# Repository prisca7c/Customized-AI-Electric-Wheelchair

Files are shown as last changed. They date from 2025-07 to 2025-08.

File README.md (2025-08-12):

# Customized-AI-Electric-Wheelchair

>PRISCA CHIEN | U0741Q95Y02
>
>July 27 2025
---

Manual wheelchair turned electric! This wheelchair uses electronic components such as modules and a PCB to make this wheelchair much for user interactive (and helps make life easier when you can't walk). 
I built this custom wheelchair because electric wheelchairs cost too much. Also it would be a great gift to my grandpa as he has Parkinson's disease. It has most of the functions on a regular wheelchair (motors, sound, speed, SOS, etc) AND I will be using AI as a healthcare tool in this project. 

---

## Full 3D Model of Wheelchair with Electronics (will not have those cuffs IRL 💀)

## PCB Schematic

## PCB Wiring Diagram (strapping 24V fan on just in case it does overheat), back copper pours for 24V, front copper pours for 12V I can't fit the wires if they're too large

## 3D View of PCB


---

# Bill of Materials (BOM)

| Reference | Qty | Description | Footprint | Purchase Link | Status |
|---|-----|---|---|---|---|
| C1,C2,C3,C4,C6,C20,C23,C25 | 8 | Polarized Capacitor | CP_Radial_D5.0mm_P2.50mm | [AliExpress](https://www.aliexpress.com/item/1005002524973878.html) | |
| C5,C7,C8,C9,C10,C11,C12,C13,C14,C15,C16,C17,C18,C19,C22,C24 | 16 | Ceramic Capacitor | C_0603_1608Metric | [AliExpress](https://www.aliexpress.com/item/33000528620.html) | |
| C21 | 1 | Ceramic Capacitor (45°) | C_0603_1608Metric | [AliExpress](https://www.aliexpress.com/item/33000528620.html) | |
| D1 | 1 | TVS Diode | D_SMA | [AliExpress](https://www.aliexpress.com/item/1005002276080010.html) | |
| D2,D3,D4,D5,D8,D9,D10,D11,D12,D13,D14,D15,D16,D17,D18,D19 | 16 | Schottky Diode | D_SMA | [AliExpress](https://www.aliexpress.com/item/4001272645647.html) | |
| D6,D7 | 2 | LED | LED_D5.0mm | - | ✅ Have |
| F1 | 1 | Fuse | Fuse_BelFuse_0ZRE0005FF | - | ✅ Have |
| J1 | 1 | Buck Converter 24V→5V | PinSocket_1x04_P2.54mm | [AliExpress](https://www.aliexpress.com/item/1005006648976219.html) | |
| J2 | 1 | Buck Converter 24V→12V | FanPinHeader_1x04_P2.54mm | [AliExpress](https://www.aliexpress.com/item/1005004705881343.html) | |
| J3 | 1 | ICSP Programming Header | PinHeader_2x03_P2.54mm | - | ✅ Have |
| J4 | 1 | USB Serial | PinHeader_1x06_P1.00mm | - | ✅ Have |
| J5 | 1 | Raspberry Pi Zero | Harwin_M20-7812045_2x20 | [AliExpress](https://www.aliexpress.com/item/1005005792181612.html) | |
| J8 | 1 | Microphone | PinHeader_1x03_P1.00mm | [AliExpress](https://www.aliexpress.com/item/4001293896057.html) | |
| J9 | 1 | TFT 3.5" Display | PinHeader_1x14_P1.00mm | [AliExpress](https://www.aliexpress.com/item/1005008990800806.html) | |
| J10 | 1 | MPU6050 IMU | PinSocket_1x08_P2.54mm | [AliExpress](https://www.aliexpress.com/item/1005005682188615.html) | |
| J11 | 1 | DS3231 RTC | PinSocket_1x06_P2.54mm | [AliExpress](https://www.aliexpress.com/item/1005007143542894.html) | |
| J12 | 1 | Ultrasonic Sensor 1 | PinHeader_1x04_P1.00mm | - | ✅ Have |
| J13 | 1 | Ultrasonic Sensor 2 | PinHeader_1x04_P1.00mm | - | ✅ Have |
| J14 | 1 | Ultrasonic Sensor 3 | PinHeader_1x04_P1.00mm | - | ✅ Have |
| J15 | 1 | GPS Module | PinHeader_1x04_P1.00mm | [AliExpress](https://www.aliexpress.com/item/1005006459556070.html) | |
| J16 | 1 | Joystick Control | PinHeader_1x05_P1.00mm | - | ✅ Have |
| J17 | 1 | Temperature Sensor 1 | PinHeader_1x03_P1.00mm | - | ✅ Have |
| J18 | 1 | Temperature Sensor 2 | PinHeader_1x03_P1.00mm | - | ✅ Have |
| J19 | 1 | Servo 1 | PinHeader_1x02_P1.00mm | - | ✅ Have |
| J20 | 1 | Servo 2 | PinHeader_1x02_P1.00mm | - | ✅ Have |
| J21 | 1 | Linear Actuator | PinHeader_1x02_P1.00mm | - | ✅ Have |
| J22 | 1 | Audio Amplifier (LM386) | PinHeader_1x06_P1.00mm | [AliExpress](https://www.aliexpress.com/item/1005007577064258.html) | |
| J23 | 1 | Speaker | PinHeader_1x02_P1.00mm | [AliExpress](https://www.aliexpress.com/item/1005007504226811.html) | |
| J24 | 1 | XT60-M Power Connector | AMASS_XT60-M | [AliExpress](https://www.aliexpress.com/item/1005008955682135.html) | |
| J25,J26 | 2 | Motor Power Terminals | TerminalBlock_Phoenix_MKDS | [AliExpress](https://www.aliexpress.com/item/1005003179482974.html) | |
| Q1,Q2,Q3,Q4 | 4 | BSS138 MOSFET | SOT-23 | [AliExpress](https://www.aliexpress.com/item/1005009546772808.html) | |
| R1-R26 | 26 | Resistor | R_0603_1608Metric | - | ✅ Have |
| SW1 | 1 | SPST Switch | SW_PUSH-12mm | [AliExpress](https://www.aliexpress.com/item/1005006921918648.html) | |
| SW2-SW9 | 8 | Push Button | SW_PUSH-12mm | [AliExpress](https://www.aliexpress.com/item/1005007791349282.html) | |
| U1 | 1 | LM7805 Voltage Regulator | TO-220-3_Vertical | [AliExpress](https://www.aliexpress.com/item/10000200087213.html) | |
| U2 | 1 | AMS1117-3.3 Regulator | SOT-223-3_TabPin2 | [AliExpress](https://www.aliexpress.com/item/1005005774011848.html) | |
| U3 | 1 | ATMEGA2560-16AU MCU | TQFP100-0.5-14X14MM | [Digi-Key](https://www.digikey.ca/en/products/detail/microchip-technology/ATMEGA2560-16AU/735455) | |
| U4,U5,U6,U7 | 4 | BTS7960B Motor Driver | DPAK127P1490X440-8N | [AliExpress](https://www.aliexpress.com/item/1005006757604804.html) | |
| U9,U10 | 2 | L298N Motor Driver | TO-220-15_P2.54x2.54mm | [AliExpress](https://www.aliexpress.com/item/1462773567.html) | |
| U11 | 1 | ESP32-C3-MINI WiFi Module | XCVR_ESP32-C3-MINI-1-N4 | [AliExpress](https://www.aliexpress.com/item/1005007446928015.html) | |
| Y1 | 1 | Crystal Oscillator | Crystal_HC49-4H_Vertical | [AliExpress](https://www.aliexpress.com/item/1005002830871853.html) | |

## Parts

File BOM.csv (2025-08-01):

Reference | Qty | Value | DNP | Exclude from BOM | Exclude from Board | Footprint | Datasheet
C1,C2,C3,C4,C6,C20,C23,C25 | 8 | C_Polarized |  |  |  | Capacitor_THT:CP_Radial_D5.0mm_P2.50mm | https://www.aliexpress.com/item/1005002524973878.html
C5,C7,C8,C9,C10,C11,C12,C13,C14,C15,C16,C17,C18,C19,C22,C24 | 16 | C |  |  |  | Capacitor_SMD:C_0603_1608Metric | https://www.aliexpress.com/item/33000528620.html
C21 | 1 | C_45deg |  |  |  | Capacitor_SMD:C_0603_1608Metric | https://www.aliexpress.com/item/33000528620.html
D1 | 1 | D_TVS |  |  |  | Diode_SMD:D_SMA | https://www.aliexpress.com/item/1005002276080010.html
D2,D3,D4,D5,D8,D9,D10,D11,D12,D13,D14,D15,D16,D17,D18,D19 | 16 | D_Schottky |  |  |  | Diode_SMD:D_SMA | https://www.aliexpress.com/item/4001272645647.html
D6,D7 | 2 | LED |  |  |  | LED_THT:LED_D5.0mm | ~already have
F1 | 1 | Fuse |  |  |  | Fuse:Fuse_BelFuse_0ZRE0005FF_L8.3mm_W3.8mm | ~already have
H1,H4 | 2 | MountingHole |  | Excluded from BOM |  | MountingHole:MountingHole_2.7mm_M2.5 | ~
H5,H6,H7,H8 | 4 | MountingHole_Pad |  | Excluded from BOM |  | MountingHole:MountingHole_3.2mm_M3_Pad | ~
H9,H10,H11,H12 | 4 | MountingHole_Pad |  | Excluded from BOM |  | MountingHole:MountingHole_3.2mm_M3_Pad_Via | ~
J1 | 1 | Buck_Converter_24V-5V |  |  |  | Connector_PinSocket_2.54mm:PinSocket_1x04_P2.54mm_Vertical_SMD_Pin1Left | https://www.aliexpress.com/item/1005006648976219.html
J2 | 1 | Buck_Converter_24V-12V |  |  |  | Connector:FanPinHeader_1x04_P2.54mm_Vertical | https://www.aliexpress.com/item/1005004705881343.html
J3 | 1 | ICSP_Programming_Header |  |  |  | Connector_PinHeader_2.54mm:PinHeader_2x03_P2.54mm_Vertical | ~already have
J4 | 1 | USB_Serial |  |  |  | Connector_PinHeader_1.00mm:PinHeader_1x06_P1.00mm_Vertical_SMD_Pin1Left | ~already have
J5 | 1 | Raspberry_Pi_Zero |  |  |  | Connector_Harwin:Harwin_M20-7812045_2x20_P2.54mm_Vertical | https://www.aliexpress.com/item/1005005792181612.html
J8 | 1 | Microphone |  |  |  | Connector_PinHeader_1.00mm:PinHeader_1x03_P1.00mm_Vertical_SMD_Pin1Left | https://www.aliexpress.com/item/4001293896057.html
J9 | 1 | TFT_3.5_Display |  |  |  | Connector_PinHeader_1.00mm:PinHeader_1x14_P1.00mm_Vertical_SMD_Pin1Left | https://www.aliexpress.com/item/1005008990800806.html
J10 | 1 | MPU6050_IMU |  |  |  | Connector_PinSocket_2.54mm:PinSocket_1x08_P2.54mm_Vertical_SMD_Pin1Left | https://www.aliexpress.com/item/1005005682188615.html
J11 | 1 | DS3231_RTC |  |  |  | Connector_PinSocket_2.54mm:PinSocket_1x06_P2.54mm_Vertical_SMD_Pin1Left | https://www.aliexpress.com/item/1005007143542894.html
J12 | 1 | Ultrasonic_Sensor_1 |  |  |  | Connector_PinHeader_1.00mm:PinHeader_1x04_P1.00mm_Vertical_SMD_Pin1Left | ~already have
J13 | 1 | Ultrasonic_Sensor_2 |  |  |  | Connector_PinHeader_1.00mm:PinHeader_1x04_P1.00mm_Vertical_SMD_Pin1Left | ~already have
J14 | 1 | Ultrasonic_Sensor_3 |  |  |  | Connector_PinHeader_1.00mm:PinHeader_1x04_P1.00mm_Vertical_SMD_Pin1Left | ~already have
J15 | 1 | GPS_Module |  |  |  | Connector_PinHeader_1.00mm:PinHeader_1x04_P1.00mm_Vertical_SMD_Pin1Left | https://www.aliexpress.com/item/1005006459556070.html
J16 | 1 | Joystick_Control |  |  |  | Connector_PinHeader_1.00mm:PinHeader_1x05_P1.00mm_Vertical_SMD_Pin1Left | ~already have
J17 | 1 | Temperature_Sensor_1 |  |  |  | Connector_PinHeader_1.00mm:PinHeader_1x03_P1.00mm_Vertical_SMD_Pin1Left | ~already have
J18 | 1 | Temperature_Sensor_2 |  |  |  | Connector_PinHeader_1.00mm:PinHeader_1x03_P1.00mm_Vertical_SMD_Pin1Left | ~already have
J19 | 1 | Servo_1 |  |  |  | Connector_PinHeader_1.00mm:PinHeader_1x02_P1.00mm_Vertical_SMD_Pin1Left | ~already have
J20 | 1 | Servo_2 |  |  |  | Connector_PinHeader_1.00mm:PinHeader_1x02_P1.00mm_Vertical_SMD_Pin1Left | ~already have
J21 | 1 | Linear_Actuator |  |  |  | Connector_PinHeader_1.00mm:PinHeader_1x02_P1.00mm_Vertical_SMD_Pin1Left | ~already have
J22 | 1 | Audio_Amplifier |  |  |  | Connector_PinHeader_1.00mm:PinHeader_1x06_P1.00mm_Vertical_SMD_Pin1Left | https://www.aliexpress.com/item/1005007577064258.html
J23 | 1 | Speaker |  |  |  | Connector_PinHeader_1.00mm:PinHeader_1x02_P1.00mm_Vertical_SMD_Pin1Left | https://www.aliexpress.com/item/1005007504226811.html
J24 | 1 | XT60-M |  |  |  | XT60-M:AMASS_XT60-M | https://www.aliexpress.com/item/1005008955682135.html
J25,J26 | 2 | Motor_1_Motor_2_Power |  |  |  | TerminalBlock_Phoenix:TerminalBlock_Phoenix_MKDS-1,5-2_1x02_P5.00mm_Horizontal | https://www.aliexpress.com/item/1005003179482974.html
Q1,Q2,Q3,Q4 | 4 | BSS138 |  |  |  | Package_TO_SOT_SMD:SOT-23 | https://www.aliexpress.com/item/1005009546772808.html
R1,R2,R3,R4,R5,R6,R7,R8,R9,R10,R11,R12,R13,R14,R15,R16,R17,R18,R19,R20,R21,R22,R23,R24,R25,R26 | 26 | R |  |  |  | Resistor_SMD:R_0603_1608Metric | ~already have
SW1 | 1 | SW_SPST |  |  |  | Button_Switch_THT:SW_PUSH-12mm | https://www.aliexpress.com/item/1005006921918648.html
SW2,SW3,SW4,SW5,SW6,SW7,SW8,SW9 | 8 | SW_Push |  |  |  | Button_Switch_THT:SW_PUSH-12mm | https://www.aliexpress.com/item/1005007791349282.html
U1 | 1 | LM7805_TO220 |  |  |  | Package_TO_SOT_THT:TO-220-3_Vertical | https://www.aliexpress.com/item/10000200087213.html
U2 | 1 | AMS1117-3.3 |  |  |  | Package_TO_SOT_SMD:SOT-223-3_TabPin2 | https://www.aliexpress.com/item/1005005774011848.html
U3 | 1 | MCU-ATMEGA2560-16AU_TQFP100_ |  |  |  | MCU-ATMEGA2560-16AU_TQFP100_:TQFP100-0.5-14X14MM | https://www.digikey.ca/en/products/detail/microchip-technology/ATMEGA2560-16AU/735455
U4,U5,U6,U7 | 4 | BTS7960B |  |  |  | BTS7960B:DPAK127P1490X440-8N | https://www.aliexpress.com/item/1005006757604804.html
U9,U10 | 2 | L298N |  |  |  | Package_TO_SOT_THT:TO-220-15_P2.54x2.54mm_StaggerOdd_Lead5.84mm_TabDown | https://www.aliexpress.com/item/1462773567.html
U11 | 1 | ESP32-C3-MINI-1-N4:E |  |  |  | ESP32-C3-MINI-1-N4:XCVR_ESP32-C3-MINI-1-N4 | https://www.aliexpress.com/item/1005007446928015.html?mp=1
Y1 | 1 | Crystal |  |  |  | Crystal:Crystal_HC49-4H_Vertical | https://www.aliexpress.com/item/1005002830871853.html

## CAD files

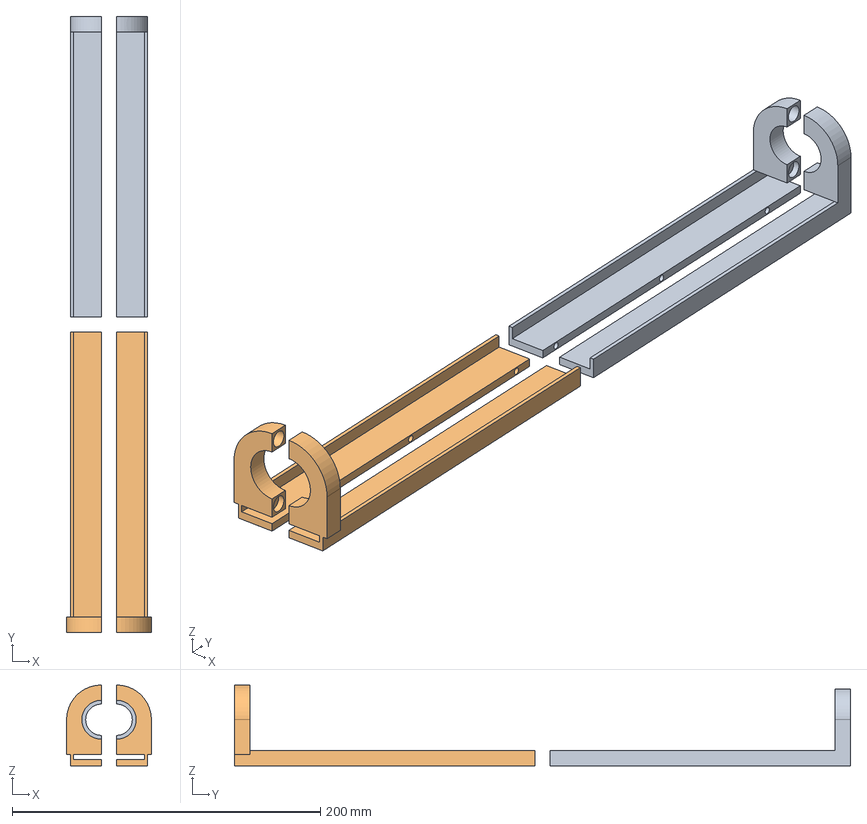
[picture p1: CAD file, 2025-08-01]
CAD/Armrest.step
55.1 x 400.0 x 52.5 mm

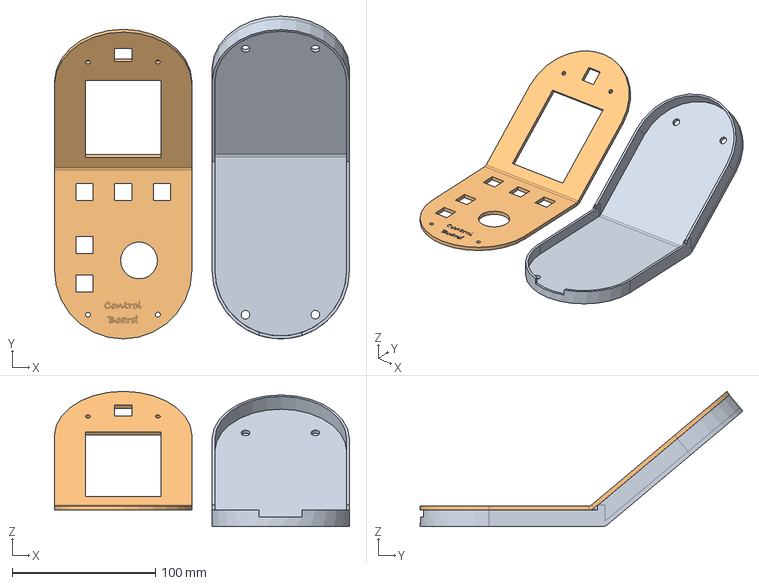
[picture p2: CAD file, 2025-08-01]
CAD/Control Board.step
206.0 x 225.4 x 94.5 mm

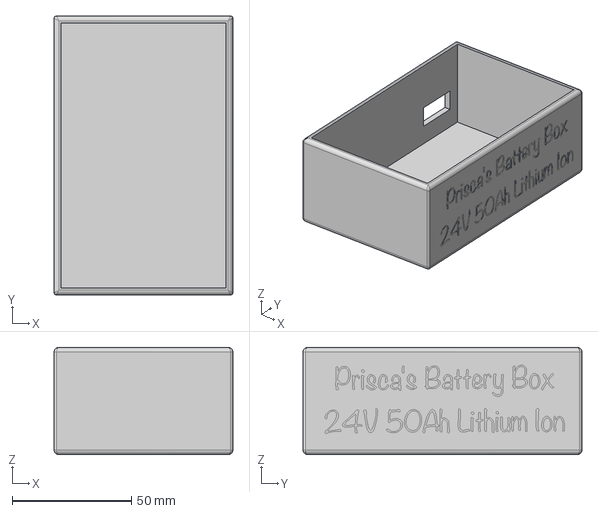
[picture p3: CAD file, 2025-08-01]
CAD/Battery Box.step
75.0 x 117.0 x 45.0 mm

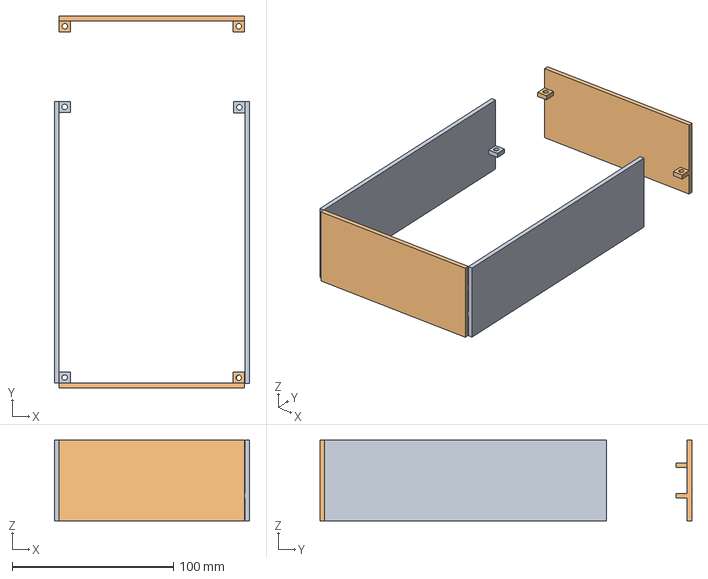
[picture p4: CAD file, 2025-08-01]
CAD/PCB Walls.step
121.2 x 231.0 x 50.0 mm

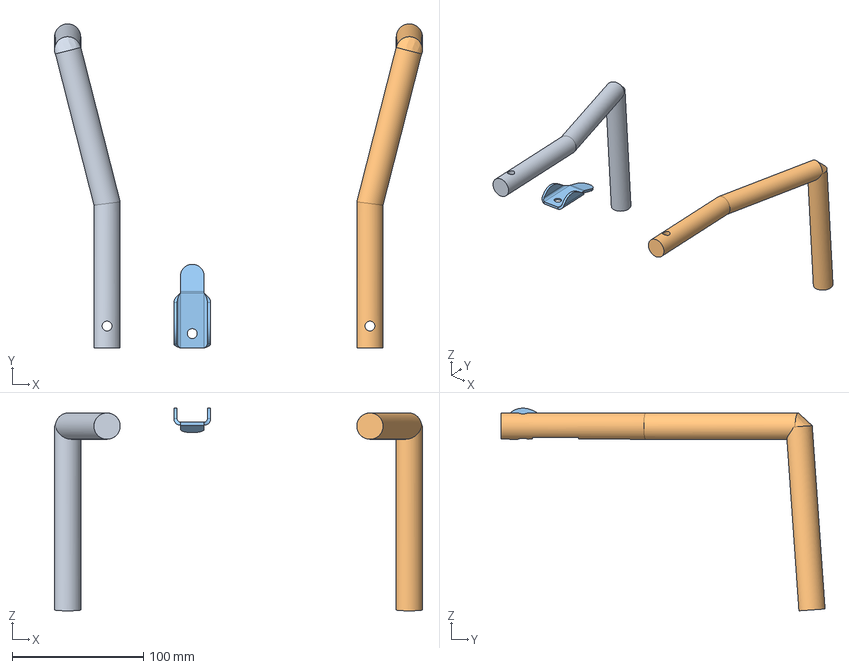
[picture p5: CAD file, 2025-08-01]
CAD/Handle and Lock Mech.step
280.0 x 246.7 x 154.2 mm

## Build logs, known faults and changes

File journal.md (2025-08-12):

# Wheelchair Project Journal!
---
TITLE: Customized AI Electric Wheelchair

AUTHOR: PRISCA CHIEN (U0741Q95Y02)

DESCRIPTION: my own motorized wheelchair with ai

CREATE DATE: July 27

---

> Prisca: 89 hours

> Updated until: Aug 10

---

### 🗓️ July 27 - 12 hrs
- started researching all the parts i need for my ai-powered electric wheelchair project. looked into battery options and decided on 24v lithium-ion packs because theyre lighter than lead acid and last longer. need about 50ah for decent runtime. specifically looking at 18650 cell packs with bms built in. calculated that at 5a continuous draw i should get around 10 hours runtime which is way better than the 4-6 hours most commercial wheelchairs get.
- spent time comparing brushless vs brushed dc motors for the wheels. brushless are more efficient but brushed are simpler to control. need enough torque to handle going up hills with a person on it. looking at 24v 350w motors with at least 80nm stall torque. found some decent planetary gearbox motors on alibaba but shipping is expensive. might go with standard wheelchair hub motors instead since theyre already designed for this application.
made a list of all the external stuff i need like joystick controller, magnetic armrest mounts, control panel with buttons, battery box, and custom circuit board. for the joystick im thinking analog hall effect sensors since they dont wear out like potentiometers. need at least 10-bit resolution for smooth control.
- figured out the communication setup - raspberry pi handles the ai and camera stuff, talks to my custom pcb via i2c or spi, which talks to an atmega2560 microcontroller for the main motor controls and safety systems, and an esp32 for wireless communication with phone app and remote monitoring. might add can bus later if i need more robust communication.
- looked at other peoples wheelchair builds online for ideas on how to lay everything out and manage all the wires. found some good ideas about using spiral cable wrap and making modular harnesses that can be unplugged for maintenance.
- biggest problem was finding parts with the right connectors and comparing prices from different suppliers. mouser and digikey are expensive but reliable, alibaba is cheap but quality is questionable. also realized i dont know much about protection circuits yet, especially for high current motor drives.
- next up is finalizing the exact parts list with all the technical specs and footprints.

---

### 🗓️ July 28 - 15 hrs
- focused on protection circuits today. learned about tvs diodes for surge protection - need bidirectional ones rated for at least 28v to handle the 24v rail spikes. schottky diodes to protect against back voltage from motors when they act like generators during braking. using 40v 10a schottky diodes on each motor output. also figured out capacitor sizing - need big electrolytic caps (1000uf+) on each voltage rail for bulk storage and smaller ceramic caps (100nf) right at each ic for high frequency noise filtering.
- decided which parts should be separate modules vs built into the main board. keeping motor drivers as separate modules because they get hot and might need replacement. also making the buck converters modular so i can swap in different voltages if needed. raspberry pi obviously stays separate. everything else like the atmega2560, esp32, and analog circuits goes on the main board.
- made almost final list of all electronic parts with exact part numbers and where to buy them. motor drivers are cytron md30c because theyre robust and have good current sensing. buck converters are lm2596 modules from aliexpress. for the microcontroller im using atmega2560 in qfp package because it has enough io pins and hardware pwm channels. esp32 is the wroom-32 module.
- took measurements of the actual wheelchair so i can design the 3d printed parts to fit. wheelchair frame tubes are 25mm diameter, seat is 18 inches wide, armrests are 24 inches long and 2 inches wide. battery box needs to fit under the seat without interfering with leg room.
- realized the power traces on the circuit board might be too thick for the available space. for 10a continuous current need at least 0.2 inch wide traces on 1oz copper but that takes up too much room. might need to use copper pours instead of just traces, or go to 2oz copper thickness.
- feel good about understanding surge protection now. ready to start drawing the schematic.



---

### 🗓️ July 29 - 17 hrs
- started designing the circuit board schematic in kicad. put the atmega2560 in the center with all the other circuits around it. used hierarchical sheets to organize different subsystems - power management, motor control, communications, and sensors each get their own sheet.
- added all the components i researched earlier. power section has main 24v input with reverse polarity protection using a p-channel mosfet, then branches to 12v and 5v buck converters. 12v rail powers the motor drivers and cooling fans, 5v rail powers all the logic circuits and raspberry pi.
for the atmega2560 i used the 100-pin tqfp package and broke out all the important pins - pwm outputs for motor control, analog inputs for current sensing, digital io for switches and status leds, and hardware serial ports for communication with raspberry pi and esp32.
- esp32 section includes the crystal oscillator, power supply filtering, and gpio breakouts for the wireless antenna connection. also added programming header so i can update firmware without removing the chip.
- analog section has op-amps for current sensing with precision shunt resistors, voltage dividers for battery monitoring, and adc filtering. used rail-to-rail op-amps since theyre running on single supply.
- finished the first version of the schematic with correct pin connections and labeled all the voltage rails (5v, 12v, 24v). double checked all the power calculations - worst case total current draw should be around 15a so 24v battery pack needs to handle that plus some safety margin.
- schematic looks solid but know the actual board layout is going to be tricky with all these connections. especially the high current motor traces and keeping the analog circuits away from switching noise.


---

### 🗓️ July 30 - 15 hrs
- worked on laying out the actual circuit board. decided on 4-layer pcb with top and bottom for components and signals, inner layers for power planes. board dimensions are 150mm x 100mm which should fit in the 3d printed housing.
- put power inputs on the left side with big screw terminals and fuses. power section with buck converters and protection circuits right next to the input. motor driver connectors on the right side with thick traces and copper pours for high current paths.
- kept the atmega2560 in the middle to minimize trace lengths to all the peripherals. crystal oscillator as close as possible to reduce noise. analog circuits in bottom left corner away from switching power supplies and digital circuits.
- positioned raspberry pi connector (40-pin header) and esp32 chip where theyll be easy to access from the housing openings. usb programming connector for atmega on the edge of the board.
- routing was a nightmare. started with power traces first - 24v, 12v, 5v, and ground. used 0.5mm traces for low current stuff, 1mm for medium current, and 2mm plus copper pours for high current motor connections. ground plane on inner layer with lots of vias for good connection.
- signal routing came next. high speed signals like spi between atmega and esp32 kept short with ground plane underneath. analog signals routed away from digital switching circuits. used differential pairs for critical signals where possible.
- finished routing all the traces but its super dense and complicated. had to use vias to jump between layers constantly. some traces had to snake around quite a bit to avoid crossing other signals.
- thinking i need more modular design for next version. maybe separate the motor drivers completely and use ribbon cables to connect them. would make the main board smaller and easier to route.


---

### 🗓️ July 31 - 14 hrs
- added mounting holes in each corner of the board with 3mm screws. also added mounting pads for any components that might need extra mechanical support like the big electrolytic capacitors and heavy connectors.
- decided to use copper pours instead of just thick traces for better heat spreading. 24v and ground get full copper pours on opposite sides of the board. 12v and 5v get smaller pours in their respective areas. this should help with both current carrying capacity and thermal management.
designed all the 3d printed parts in fusion 360:
- magnetic armrest mount - uses 20mm neodymium magnets embedded in both the armrest and wheelchair frame mount. magnets are strong enough to hold the armrest securely but can be detached for transport. includes cable routing channels for the control panel wires.
- walker handle with locking mechanism - modeled after standard wheelchair handles but with a spring loaded pin that locks into the frame. handle folds down when not in use. includes rubber grip and emergency stop button.
- battery box for 24v pack - completely enclosed box that mounts under the seat. has ventilation holes and a cooling fan. includes bms mounting area and main power switch. box is split into two parts for easier 3d printing.
- pcb housing - two part enclosure with mounting posts for the circuit board. front and back are open for airflow and connector access. includes cable management features and mounting holes to attach to wheelchair frame.
- control panel with 6 buttons plus analog joystick - waterproof membrane switches with tactile feedback. joystick is hall effect type for reliability. panel mounts to the armrest via magnetic connector so it can be removed for cleaning or replacement.
- created github repository "ai-wheelchair" to store all my design files. organized into folders for mechanical parts, electronics, firmware, and documentation.
- all the mechanical parts need to work together with the electronics placement. spent time making sure connector locations on the pcb line up with cable routing in the 3d printed parts.

## Battery Box

## Close-up of PCB Wall

## User Control Panel (external modules connected here)

## Handle with Lock Mechanism

## PCB Protection (elevated so I can cool it easily and also connect heatsinks and thermal pads and stuff. ALso the walls are connected with straps to legs of wheelchair)

## Close-up of Lock Mechanism (will superglue spring and magnet)

## Wire Support on Armrest


---

### 🗓️ August 6 - 4 hrs
- modeled the whole wheelchair in cad using real measurements. main frame is welded steel tube construction, seat dimensions are 18" wide by 16" deep, backrest is 18" tall. integrated the battery box under the seat - had to adjust dimensions to clear the cross braces and leave room for user's legs.
- pcb housing mounts to the frame behind the seat where its protected but still accessible. used aluminum angle brackets to attach to the frame tubes. housing is positioned so all the connectors face outward for easy cable access.
- added space for extra buck converter module on the pcb for voltage flexibility. thinking i might need 9v or 15v for some sensors later so having an empty module slot is good future proofing.
- changed some connectors from molex to screw terminals for easier field connections. also switched some headers from through-hole to surface mount to save space. used pogo pin connectors for programming headers so they dont take up permanent board space.
- updated the 3d models to match the real wheelchair measurements. had to adjust battery box height to clear the seat cushion and make the cable routing work properly.

## Control Panel and Wiring through Armrest

## Walker Handle and Lock Mechanism (my actual wheelchair can pull down the backrest)

## PCB Walls and Battery Box will be connected via straps to the 4 bars of the wheelchair legs


---

### 🗓️ August 7-9 - 10 hrs
- learned about thermal management for pcbs. thermal vias are basically small holes filled with copper that transfer heat from hot components on top of the board down to the ground plane for heat spreading. added thermal vias under the atmega2560, voltage regulators, and motor driver connectors.
- set up net classes in kicad to automatically manage trace widths. power nets get thick traces (1-2mm), high speed signals get controlled impedance (0.15mm with specific spacing), and regular io gets standard 0.1mm traces. this makes routing much more consistent and professional looking.
- copper pours are basically large areas of copper connected to specific nets. used copper pours for the main voltage rails and ground. 24v pour covers most of the top layer around the power section, 12v pour covers the motor driver area, 5v pour covers the logic section, and ground pour covers the entire bottom layer.
- made all high current traces as wide as possible - 2mm for motor outputs, 1.5mm for main power rails, 1mm for buck converter inputs. where traces couldnt be wide enough i overlaid copper pours to carry the extra current and spread heat.
- rerouted major power and ground connections to pass design rule checks with no errors. kicad checks for things like minimum trace width, via sizes, drill holes, copper clearances, and electrical rule violations. took several iterations to get everything clean.
- planned passive cooling strategy using the open pcb housing design. hot components like voltage regulators and the atmega2560 are positioned near the housing openings where airflow can carry heat away. might add a small 12v fan later if needed but trying to avoid the noise and complexity for now.
- added temperature monitoring with thermistors near the hottest components so the software can throttle performance or shut down if things get too hot.

---

### 🗓️ August 10 - 2 hrs
- finished applying copper pours - 12v on front layer and 24v on back layer. double checked that pours dont create shorts and respect all the net boundaries.
- updated project files and made renders of the final design.


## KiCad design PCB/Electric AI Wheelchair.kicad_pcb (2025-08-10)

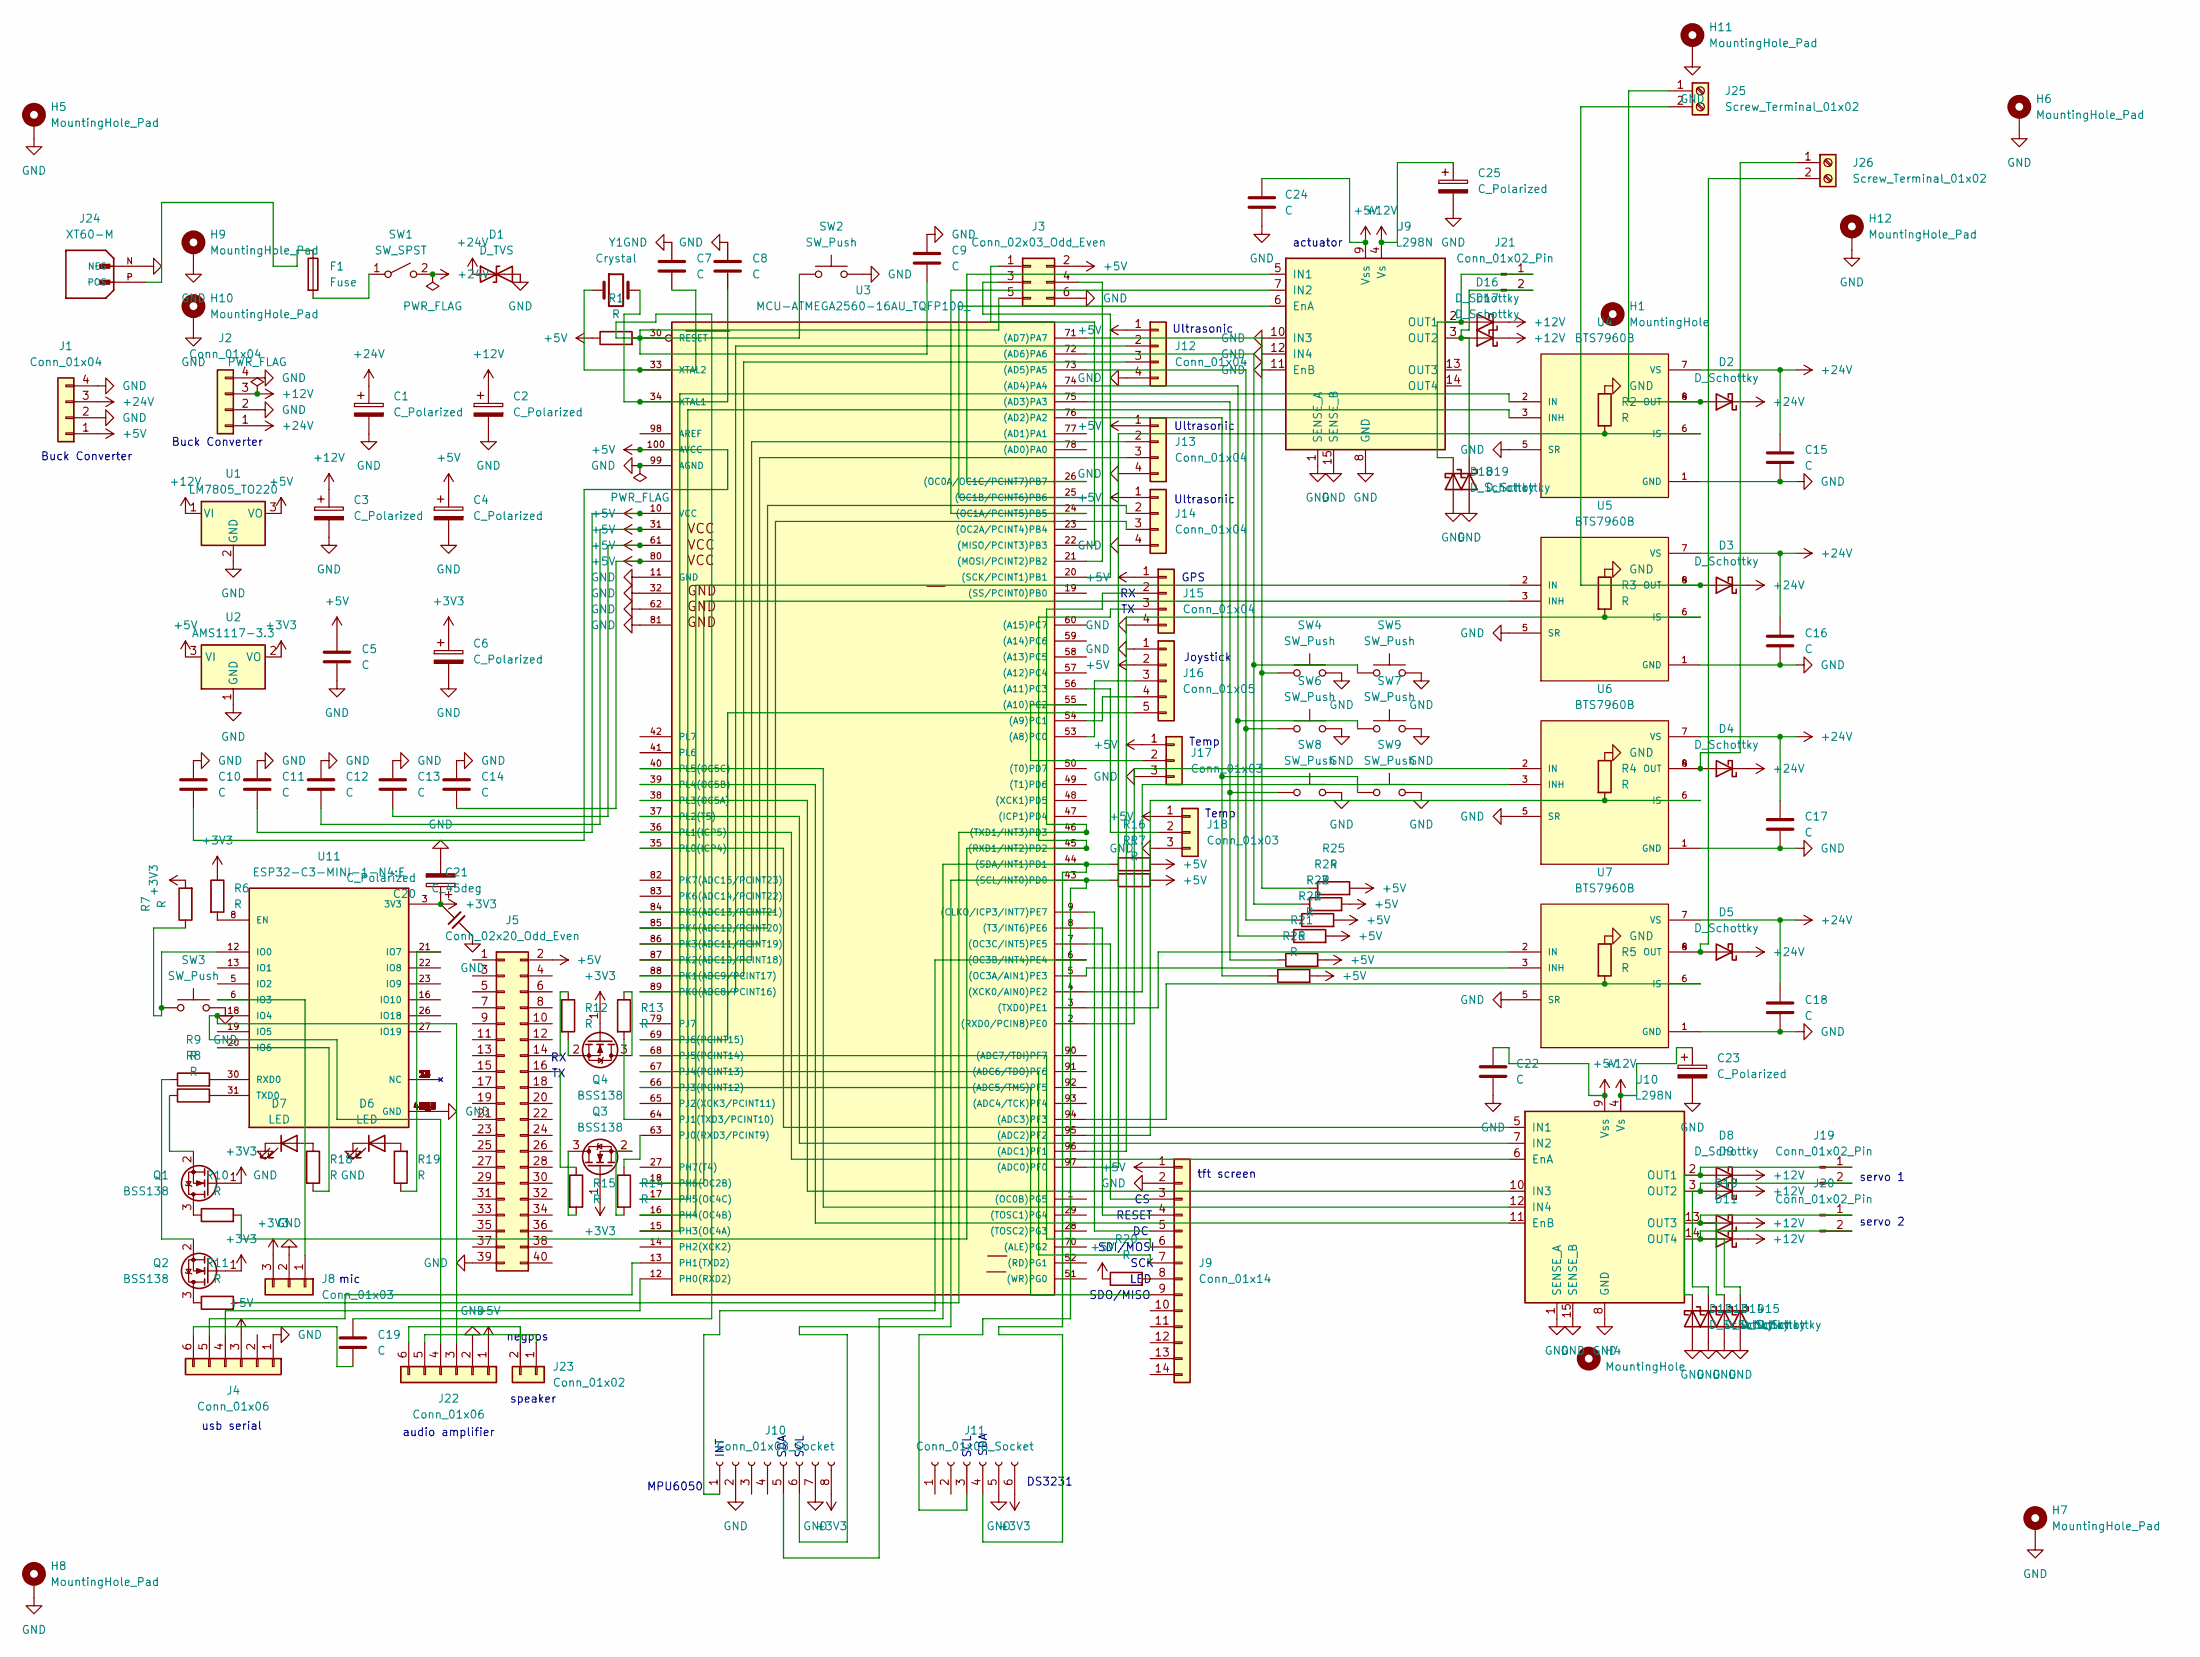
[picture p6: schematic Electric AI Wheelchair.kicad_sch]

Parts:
C1, C2, C3, C4, C6, C20, C23, C25: C_Polarized; CP_Radial_D5.0mm_P2.50mm
C5, C7, C8, C9, C10, C11, C12, C13, C14, C15, C16, C17, C18, C19, C22, C24: C; C_0603_1608Metric
C21: C_45deg; C_0603_1608Metric
D1: D_TVS; D_SMA
D2, D3, D4, D5, D8, D9, D10, D11, D12, D13, D14, D15, D16, D17, D18, D19: D_Schottky; D_SMA
D6, D7: LED; LED_D5.0mm
F1: Fuse; Fuse_BelFuse_0ZRE0005FF_L8.3mm_W3.8mm
H1, H4: MountingHole; MountingHole_2.7mm_M2.5
H5, H6, H7, H8: MountingHole_Pad; MountingHole_3.2mm_M3_Pad
H9, H10, H11, H12: MountingHole_Pad; MountingHole_3.2mm_M3_Pad_Via
J1: Conn_01x04; PinSocket_1x04_P2.54mm_Vertical_SMD_Pin1Left
J2: Conn_01x04; FanPinHeader_1x04_P2.54mm_Vertical
J3: Conn_02x03_Odd_Even; PinHeader_2x03_P2.54mm_Vertical
J4, J22: Conn_01x06; PinHeader_1x06_P1.00mm_Vertical_SMD_Pin1Left
J5: Conn_02x20_Odd_Even; Harwin_M20-7812045_2x20_P2.54mm_Vertical
J8, J17, J18: Conn_01x03; PinHeader_1x03_P1.00mm_Vertical_SMD_Pin1Left
J9: Conn_01x14; PinHeader_1x14_P1.00mm_Vertical_SMD_Pin1Left
J10: Conn_01x08_Socket; PinSocket_1x08_P2.54mm_Vertical_SMD_Pin1Left
J11: Conn_01x06_Socket; PinSocket_1x06_P2.54mm_Vertical_SMD_Pin1Left
J12, J13, J14, J15: Conn_01x04; PinHeader_1x04_P1.00mm_Vertical_SMD_Pin1Left
J16: Conn_01x05; PinHeader_1x05_P1.00mm_Vertical_SMD_Pin1Left
J19, J20, J21: Conn_01x02_Pin; PinHeader_1x02_P1.00mm_Vertical_SMD_Pin1Left
J23: Conn_01x02; PinHeader_1x02_P1.00mm_Vertical_SMD_Pin1Left
J24: XT60-M; AMASS_XT60-M; PARTREV V1.2
J25, J26: Screw_Terminal_01x02; TerminalBlock_Phoenix_MKDS-1,5-2_1x02_P5.00mm_Horizontal
Q1, Q2, Q3, Q4: BSS138; SOT-23
R1, R2, R3, R4, R5, R6, R7, R8, R9, R10, R11, R12, R13, R14, R15, R16, R17, R18, R19, R20, R21, R22, R23, R24, R25, R26: R; R_0603_1608Metric
SW1: SW_SPST; SW_PUSH-12mm
SW2, SW3, SW4, SW5, SW6, SW7, SW8, SW9: SW_Push; SW_PUSH-12mm
U1: LM7805_TO220; TO-220-3_Vertical
U2: AMS1117-3.3; SOT-223-3_TabPin2
U3: MCU-ATMEGA2560-16AU_TQFP100_; TQFP100-0.5-14X14MM; MPN ATMEGA2560-16AU
U4, U5, U6, U7: BTS7960B; DPAK127P1490X440-8N; PARTREV 1.1
U9, U10: L298N; TO-220-15_P2.54x2.54mm_StaggerOdd_Lead5.84mm_TabDown
U11: ESP32-C3-MINI-1-N4:E; XCVR_ESP32-C3-MINI-1-N4; PARTREV v1.0
Y1: Crystal; Crystal_HC49-4H_Vertical

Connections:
+3V3: C6.1, C20.1, C21.2, J8.3, J10.8, J11.6, Q1.1 (G), Q2.1 (G), Q3.1 (G), Q4.1 (G), R6.1, R7.2, U2.2 (VO), U11.3 (3V3)
+5V: C4.1, C5.1, C10.2, C11.2, C12.2, C13.2, C14.2, C22.1, C24.1, J1.1, J3.2, J4.3, J5.2, J9.1, J12.1, J13.1, J14.1, J15.1, J16.2, J17.1, J18.1, J22.1, R1.1, R16.2, R17.2, R20.1, R21.2, R22.2, R23.2, R24.2, R25.2, R26.2, U1.3 (VO), U2.3 (VI), U3.10 (VCC), U3.31, U3.61, U3.80, U3.100 (AVCC), U9.9 (Vss), U10.9 (Vss)
+12V: C2.1, C3.1, C23.1, C25.1, D8.1 (K), D9.1 (K), D10.1 (K), D11.1 (K), D16.1 (K), D17.1 (K), J2.3, U1.1 (VI), U9.4 (Vs), U10.4 (Vs)
+24V: C1.1, C15.1, C16.1, C17.1, C18.1, D1.1 (A1), D2.1 (K), D3.1 (K), D4.1 (K), D5.1 (K), J1.3, J2.1, SW1.2 (B), U4.7 (VS), U5.7 (VS), U6.7 (VS), U7.7 (VS)
GND: C1.2, C2.2, C3.2, C4.2, C5.2, C6.2, C7.1, C8.1, C9.1, C10.1, C11.1, C12.1, C13.1, C14.1, C15.2, C16.2, C17.2, C18.2, C20.2, C21.1, C22.2, C23.2, C24.2, C25.2, D1.2 (A2), D6.1 (K), D7.1 (K), D12.2 (A), D13.2 (A), D14.2 (A), D15.2 (A), D18.2 (A), D19.2 (A), H5.1, H6.1, H7.1, H8.1, H9.1, H10.1, H11.1, H12.1, J1.2, J1.4, J2.2, J2.4, J3.6, J4.1, J5.39, J8.2, J9.2, J10.2, J10.7, J11.5, J12.4, J13.4, J14.4, J15.4, J16.1, J17.3, J18.3, J22.2, J24.N (NEG), R2.1, R3.1, R4.1, R5.1, SW2.2, SW3.2, SW4.2, SW5.2, SW6.2, SW7.2, SW8.2, SW9.2, U1.2 (GND), U2.1 (GND), U3.11 (GND), U3.32, U3.62, U3.81, U3.99 (AGND), U4.1 (GND), U4.5 (SR), U5.1 (GND), U5.5 (SR), U6.1 (GND), U6.5 (SR), U7.1 (GND), U7.5 (SR), U9.1 (SENSE_A), U9.8 (GND), U9.10 (IN3), U9.11 (EnB), U9.12 (IN4), U9.15 (SENSE_B), U10.1 (SENSE_A), U10.8 (GND), U10.15 (SENSE_B), U11.1 (GND), U11.2 (GND), U11.11 (GND), U11.14 (GND), U11.36 (GND), U11.37 (GND), U11.38 (GND), U11.39 (GND), U11.40 (GND), U11.41 (GND), U11.42 (GND), U11.43 (GND), U11.44 (GND), U11.45 (GND), U11.46 (GND), U11.47 (GND), U11.48 (GND), U11.49_1 (GND), U11.49_2 (GND), U11.49_3 (GND), U11.49_4 (GND), U11.49_5 (GND), U11.49_6 (GND), U11.49_7 (GND), U11.49_8 (GND), U11.49_9 (GND), U11.50 (GND), U11.51 (GND), U11.52 (GND), U11.53 (GND)
unnamed: D2.2 (A), J25.1, U4.4 (OUT), U4.8 (OUT)
unnamed: D3.2 (A), J25.2, U5.4 (OUT), U5.8 (OUT)
unnamed: D4.2 (A), J26.1, U6.4 (OUT), U6.8 (OUT)
unnamed: D5.2 (A), J26.2, U7.4 (OUT), U7.8 (OUT)
unnamed: D6.2 (A), R19.2
unnamed: D7.2 (A), R18.1
unnamed: D10.2 (A), D14.1 (K), J20.1, U10.13 (OUT3)
unnamed: D11.2 (A), D15.1 (K), J20.2, U10.14 (OUT4)
unnamed: D8.2 (A), D12.1 (K), J19.1, U10.2 (OUT1)
unnamed: D9.2 (A), D13.1 (K), J19.2, U10.3 (OUT2)
unnamed: D16.2 (A), D18.1 (K), J21.1, U9.2 (OUT1)
unnamed: D17.2 (A), D19.1 (K), J21.2, U9.3 (OUT2)
unnamed: J3.1, U3.22 ((MISO/PCINT3)PB3)
unnamed: J3.3, U3.20 ((SCK/PCINT1)PB1)
unnamed: J3.4, U3.21 ((MOSI/PCINT2)PB2)
unnamed: C9.2, C19.1, J3.5, R1.2, SW2.1, U3.30 (RESET)
unnamed: J4.4, U3.12 (PH0(RXD2))
unnamed: J4.5, U3.13 (PH1(TXD2))
unnamed: C19.2, J4.6
unnamed: J5.14, R12.1
unnamed: J5.16, R15.1
unnamed: J8.1, U11.6 (IO3)
unnamed: J9.3, U3.7 ((OC3C/INT5)PE5)
unnamed: J9.4, U3.8 ((T3/INT6)PE6)
unnamed: J9.5, U3.9 ((CLKO/ICP3/INT7)PE7)
unnamed: J9.6, U3.68 (PJ5(PCINT14))
unnamed: J9.7, U3.67 (PJ4(PCINT13))
unnamed: J9.8, R20.2
unnamed: J9.9, U3.66 (PJ3(PCINT12))
unnamed: J10.1, U3.6 ((OC3B/INT4)PE4)
unnamed: J10.5, J11.4, R16.1, U3.44 ((SDA/INT1)PD1)
unnamed: J10.6, J11.3, R17.1, U3.43 ((SCL/INT0)PD0)
unnamed: J12.2, U3.89 (PK0(ADC8/PCINT16))
unnamed: J12.3, U3.88 (PK1(ADC9/PCINT17))
unnamed: J13.2, U3.87 (PK2(ADC10/PCINT18))
unnamed: J13.3, U3.86 (PK3(ADC11/PCINT19))
unnamed: J14.2, U3.85 (PK4(ADC12/PCINT20))
unnamed: J14.3, U3.84 (PK5(ADC13/PCINT21))
unnamed: J15.2, R11.2, U3.46 ((TXD1/INT3)PD3)
unnamed: J15.3, R10.2, U3.45 ((RXD1/INT2)PD2)
unnamed: J16.3, U3.53 ((A8)PC0)
unnamed: J16.4, U3.54 ((A9)PC1)
unnamed: J16.5, U3.69 (PJ6(PCINT15))
unnamed: J17.2, U3.55 ((A10)PC2)
unnamed: J18.2, U3.56 ((A11)PC3)
unnamed: J22.3, J22.4, U11.18 (IO4)
unnamed: J22.5, J23.1
unnamed: J22.6, J23.2
unnamed: F1.1, J24.P (POS)
unnamed: Q1.3 (D), R10.1
unnamed: Q1.2 (S), R8.1
unnamed: Q2.3 (D), R11.1
unnamed: Q2.2 (S), R9.1
unnamed: Q3.3 (D), R15.2
unnamed: Q3.2 (S), R14.2
unnamed: Q4.3 (D), R13.1
unnamed: Q4.2 (S), R12.2
unnamed: F1.2, SW1.1 (A)
unnamed: R26.1, SW9.1, U3.76 ((AD2)PA2)
unnamed: R21.1, SW8.1, U3.75 ((AD3)PA3)
unnamed: R22.1, SW7.1, U3.74 ((AD4)PA4)
unnamed: R23.1, SW6.1, U3.73 ((AD5)PA5)
unnamed: R24.1, SW5.1, U3.72 ((AD6)PA6)
unnamed: R25.1, SW4.1, U3.71 ((AD7)PA7)
unnamed: R2.2, U3.97 ((ADC0)PF0), U4.6 (IS)
unnamed: R3.2, U3.96 ((ADC1)PF1), U5.6 (IS)
unnamed: R4.2, U3.95 ((ADC2)PF2), U6.6 (IS)
unnamed: R5.2, U3.94 ((ADC3)PF3), U7.6 (IS)
unnamed: U3.26 ((OC0A/OC1C/PCINT7)PB7), U9.5 (IN1)
unnamed: U3.24 ((OC1A/PCINT5)PB5), U9.7 (IN2)
unnamed: U3.25 ((OC1B/PCINT6)PB6), U9.6 (EnA)
unnamed: U3.5 ((OC3A/AIN1)PE3), U7.3 (INH)
unnamed: U3.2 ((RXD0/PCIN8)PE0), U6.2 (IN)
unnamed: U3.3 ((TXD0)PE1), U7.2 (IN)
unnamed: U3.4 ((XCK0/AIN0)PE2), U6.3 (INH)
unnamed: U3.15 (PH3(OC4A)), U4.2 (IN)
unnamed: U3.16 (PH4(OC4B)), U5.2 (IN)
unnamed: U3.17 (PH5(OC4C)), U4.3 (INH)
unnamed: U3.18 (PH6(OC2B)), U5.3 (INH)
unnamed: R14.1, U3.63 (PJ0(RXD3/PCINT9))
unnamed: R13.2, U3.64 (PJ1(TXD3/PCINT10))
unnamed: C8.2, U3.34 (XTAL1), Y1.2
unnamed: C7.2, U3.33 (XTAL2), Y1.1
unnamed: U3.36 (PL1(ICP5)), U10.6 (EnA)
unnamed: U3.39 (PL4(OC5B)), U10.11 (EnB)
unnamed: U3.35 (PL0(ICP4)), U10.5 (IN1)
unnamed: U3.37 (PL2(T5)), U10.7 (IN2)
unnamed: U3.38 (PL3(OC5A)), U10.10 (IN3)
unnamed: U3.40 (PL5(OC5C)), U10.12 (IN4)
unnamed: R6.2, U11.8 (EN)
unnamed: R7.1, SW3.1, U11.12 (IO0)
unnamed: R18.2, U11.20 (IO6)
unnamed: R19.1, U11.21 (IO7)
unnamed: R9.2, U11.30 (RXD0)
unnamed: R8.2, U11.31 (TXD0)

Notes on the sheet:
SCL
Buck Converter
servo 2
SCK
speaker
Temp
SDO/MISO
audio amplifier
Ultrasonic
LED
mic
SDI/MOSI
SDA
servo 1
INT
usb serial
GPS
Joystick
tft screen
RESET
MPU6050
actuator
neg
DS3231
pos

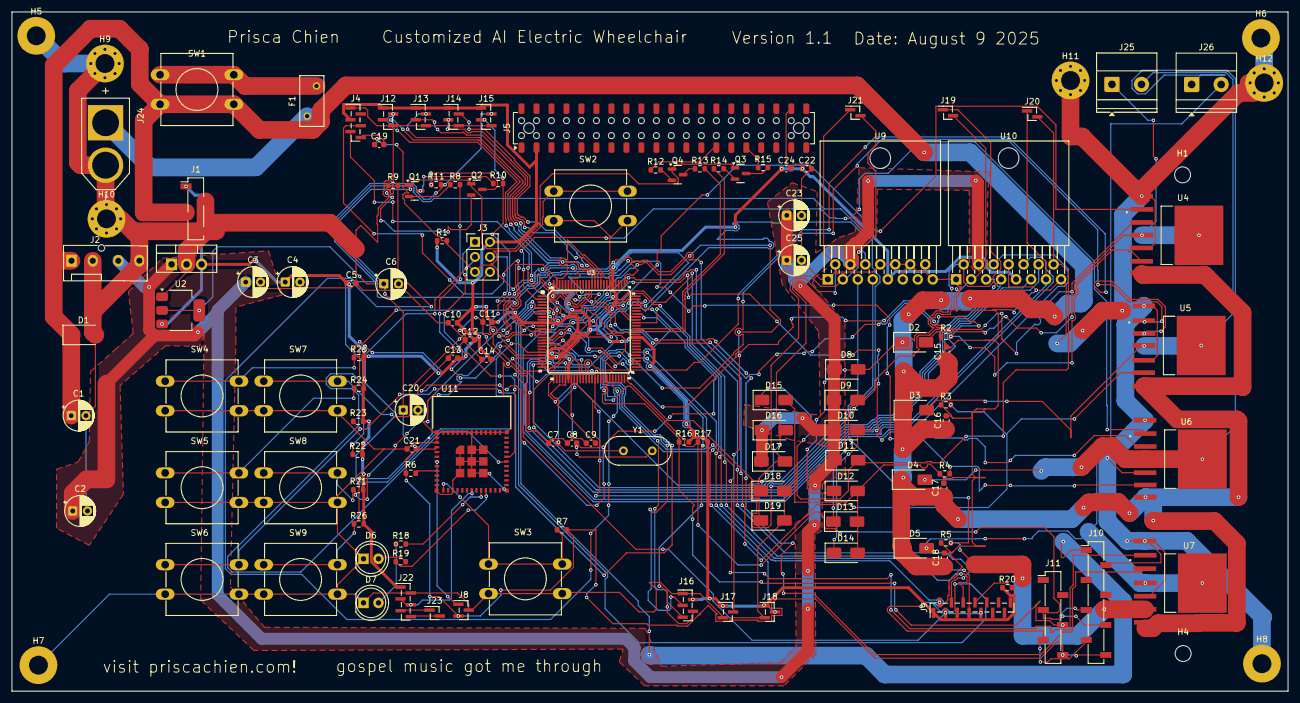
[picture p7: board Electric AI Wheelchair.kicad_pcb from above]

Board: 2 copper layers, 216.3 x 115.1 mm, 129 parts (0 on the bottom side), 100 nets.

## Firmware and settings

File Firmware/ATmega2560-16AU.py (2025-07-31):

Arduino IDE Install:
- MPU6050 by Electronic Cats
- RTClib by Adafruit
- TinyGPSPlus by Mikal Hart
- NewPing by Tim Eckel




#include <Wire.h>
#include <MPU6050.h>
#include <RTClib.h>
#include <TinyGPS++.h>
#include <NewPing.h>

#define MOTOR1_RPWM 2
#define MOTOR1_LPWM 3
#define MOTOR1_R_EN 4
#define MOTOR1_L_EN 5
#define MOTOR1_R_IS A0
#define MOTOR1_L_IS A1
#define MOTOR2_RPWM 6
#define MOTOR2_LPWM 7
#define MOTOR2_R_EN 8
#define MOTOR2_L_EN 9
#define MOTOR2_R_IS A2
#define MOTOR2_L_IS A3
#define JOYSTICK_X A4
#define JOYSTICK_Y A5
#define JOYSTICK_BTN 22
#define BTN_EMERGENCY 23
#define BTN_SPEED_UP 24
#define BTN_SPEED_DOWN 25
#define BTN_MODE 26
#define BTN_HORN 27
#define BTN_LIGHTS 28
#define BTN_AI_ASSIST 29
#define BTN_CUSTOM1 30
#define BTN_CUSTOM2 31
#define TRIG_FRONT 32
#define ECHO_FRONT 33
#define TRIG_LEFT 34
#define ECHO_LEFT 35
#define TRIG_RIGHT 36
#define ECHO_RIGHT 37
#define BATTERY_VOLTAGE A6
#define FAN_CONTROL 38
#define LED_STATUS 39
#define BUZZER 40
#define ESP32_RX 16
#define ESP32_TX 17
#define GPS_RX 18
#define GPS_TX 19

#define SPEED_SLOW 100
#define SPEED_MEDIUM 180
#define SPEED_FAST 255
#define OBSTACLE_STOP_CM 30
#define OBSTACLE_SLOW_CM 100
#define MOTOR_CURRENT_LIMIT 30.0
#define BATTERY_LOW_VOLTAGE 22.0
#define BATTERY_CRITICAL 20.0
#define JOYSTICK_DEADZONE 50
#define JOYSTICK_CENTER 512
#define RAMP_RATE 5
#define TURN_RATE_FACTOR 0.7

MPU6050 mpu;
RTC_DS3231 rtc;
TinyGPSPlus gps;
NewPing sonarFront(TRIG_FRONT, ECHO_FRONT, 400);
NewPing sonarLeft(TRIG_LEFT, ECHO_LEFT, 400);
NewPing sonarRight(TRIG_RIGHT, ECHO_RIGHT, 400);

bool emergencyStop = false;
bool systemReady = false;
uint8_t speedMode = 1;
uint8_t controlMode = 0;
bool lightsOn = false;
bool fanOn = false;

int16_t currentSpeed1 = 0;
int16_t currentSpeed2 = 0;
int16_t targetSpeed1 = 0;
int16_t targetSpeed2 = 0;

float batteryVoltage = 24.0;
float motor1Current = 0.0;
float motor2Current = 0.0;
int16_t accelX, accelY, accelZ;
int16_t gyroX, gyroY, gyroZ;
uint16_t distanceFront = 400;
uint16_t distanceLeft = 400;
uint16_t distanceRight = 400;

double latitude = 0.0;
double longitude = 0.0;
float gpsSpeed = 0.0;
uint8_t satellites = 0;

unsigned long lastMotorUpdate = 0;
unsigned long lastSensorRead = 0;
unsigned long lastBatteryCheck = 0;
unsigned long lastGPSRead = 0;
unsigned long lastStatusBlink = 0;

char espBuffer[100];
uint8_t espBufferIndex = 0;

void setup() {
  Serial.begin(115200);
  Serial1.begin(9600);
  Serial2.begin(115200);
  
  pinMode(MOTOR1_RPWM, OUTPUT);
  pinMode(MOTOR1_LPWM, OUTPUT);
  pinMode(MOTOR1_R_EN, OUTPUT);
  pinMode(MOTOR1_L_EN, OUTPUT);
  pinMode(MOTOR2_RPWM, OUTPUT);
  pinMode(MOTOR2_LPWM, OUTPUT);
  pinMode(MOTOR2_R_EN, OUTPUT);
  pinMode(MOTOR2_L_EN, OUTPUT);
  
  digitalWrite(MOTOR1_R_EN, HIGH);
  digitalWrite(MOTOR1_L_EN, HIGH);
  digitalWrite(MOTOR2_R_EN, HIGH);
  digitalWrite(MOTOR2_L_EN, HIGH);
  
  pinMode(BTN_EMERGENCY, INPUT_PULLUP);
  pinMode(BTN_SPEED_UP, INPUT_PULLUP);
  pinMode(BTN_SPEED_DOWN, INPUT_PULLUP);
  pinMode(BTN_MODE, INPUT_PULLUP);
  pinMode(BTN_HORN, INPUT_PULLUP);
  pinMode(BTN_LIGHTS, INPUT_PULLUP);
  pinMode(BTN_AI_ASSIST, INPUT_PULLUP);
  pinMode(BTN_CUSTOM1, INPUT_PULLUP);
  pinMode(BTN_CUSTOM2, INPUT_PULLUP);
  pinMode(JOYSTICK_BTN, INPUT_PULLUP);
  
  pinMode(FAN_CONTROL, OUTPUT);
  pinMode(LED_STATUS, OUTPUT);
  pinMode(BUZZER, OUTPUT);
  
  Wire.begin();
  mpu.initialize();
  rtc.begin();
  
  tone(BUZZER, 1000, 200);
  delay(200);
  tone(BUZZER, 1500, 200);
  
  systemReady = true;
}

void loop() {
  if (digitalRead(BTN_EMERGENCY) == LOW) {
    emergencyStop = true;
    stopMotors();
  }
  
  handleButtons();
  
  if (millis() - lastSensorRead >= 20) {
    readSensors();
    lastSensorRead = millis();
  }
  
  if (millis() - lastMotorUpdate >= 10 && !emergencyStop) {
    updateMotorControl();
    lastMotorUpdate = millis();
  }
  
  if (millis() - lastBatteryCheck >= 1000) {
    checkBattery();
    lastBatteryCheck = millis();
  }
  
  if (millis() - lastGPSRead >= 200) {
    updateGPS();
    lastGPSRead = millis();
  }
  
  handleESP32Communication();
  updateStatusLED();
  manageCooling();
}

void updateMotorControl() {
  int joyX = analogRead(JOYSTICK_X);
  int joyY = analogRead(JOYSTICK_Y);
  
  if (abs(joyX - JOYSTICK_CENTER) < JOYSTICK_DEADZONE) joyX = JOYSTICK_CENTER;
  if (abs(joyY - JOYSTICK_CENTER) < JOYSTICK_DEADZONE) joyY = JOYSTICK_CENTER;
  
  int16_t xSpeed = map(joyX, 0, 1023, -255, 255);
  int16_t ySpeed = map(joyY, 0, 1023, -255, 255);
  
  int maxSpeed = SPEED_MEDIUM;
  switch(speedMode) {
    case 0: maxSpeed = SPEED_SLOW; break;
    case 1: maxSpeed = SPEED_MEDIUM; break;
    case 2: maxSpeed = SPEED_FAST; break;
  }
  
  targetSpeed1 = constrain(ySpeed + (xSpeed * TURN_RATE_FACTOR), -maxSpeed, maxSpeed);
  targetSpeed2 = constrain(ySpeed - (xSpeed * TURN_RATE_FACTOR), -maxSpeed, maxSpeed);
  
  if (controlMode == 1) {
    applyObstacleAvoidance();
  }
  
  if (currentSpeed1 < targetSpeed1) {
    currentSpeed1 = min(currentSpeed1 + RAMP_RATE, targetSpeed1);
  } else if (currentSpeed1 > targetSpeed1) {
    currentSpeed1 = max(currentSpeed1 - RAMP_RATE, targetSpeed1);
  }
  
  if (currentSpeed2 < targetSpeed2) {
    currentSpeed2 = min(currentSpeed2 + RAMP_RATE, targetSpeed2);
  } else if (currentSpeed2 > targetSpeed2) {
    currentSpeed2 = max(currentSpeed2 - RAMP_RATE, targetSpeed2);
  }
  
  if (motor1Current > MOTOR_CURRENT_LIMIT || motor2Current > MOTOR_CURRENT_LIMIT) {
    currentSpeed1 = currentSpeed1 * 0.8;
    currentSpeed2 = currentSpeed2 * 0.8;
    tone(BUZZER, 2000, 100);
  }
  
  setMotor1Speed(currentSpeed1);
  setMotor2Speed(currentSpeed2);
}

void setMotor1Speed(int16_t speed) {
  if (speed > 0) {
    analogWrite(MOTOR1_RPWM, speed);
    analogWrite(MOTOR1_LPWM, 0);
  } else if (speed < 0) {
    analogWrite(MOTOR1_RPWM, 0);
    analogWrite(MOTOR1_LPWM, -speed);
  } else {
    analogWrite(MOTOR1_RPWM, 0);
    analogWrite(MOTOR1_LPWM, 0);
  }
}

void setMotor2Speed(int16_t speed) {
  if (speed > 0) {
    analogWrite(MOTOR2_RPWM, speed);
    analogWrite(MOTOR2_LPWM, 0);
  } else if (speed < 0) {
    analogWrite(MOTOR2_RPWM, 0);
    analogWrite(MOTOR2_LPWM, -speed);
  } else {
    analogWrite(MOTOR2_RPWM, 0);
    analogWrite(MOTOR2_LPWM, 0);
  }
}

void stopMotors() {
  currentSpeed1 = 0;
  currentSpeed2 = 0;
  targetSpeed1 = 0;
  targetSpeed2 = 0;
  setMotor1Speed(0);
  setMotor2Speed(0);
}

void readSensors() {
  static uint8_t sensorIndex = 0;
  switch(sensorIndex) {
    case 0:
      distanceFront = sonarFront.ping_cm();
      if (distanceFront == 0) distanceFront = 400;
      break;
    case 1:
      distanceLeft = sonarLeft.ping_cm();
      if (distanceLeft == 0) distanceLeft = 400;
      break;
    case 2:
      distanceRight = sonarRight.ping_cm();
      if (distanceRight == 0) distanceRight = 400;
      break;
  }
  sensorIndex = (sensorIndex + 1) % 3;
  
  static uint8_t mpuCounter = 0;
  if (++mpuCounter >= 3) {
    mpuCounter = 0;
    mpu.getMotion6(&accelX, &accelY, &accelZ, &gyroX, &gyroY, &gyroZ);
  }
  
  int raw1 = analogRead(MOTOR1_R_IS) + analogRead(MOTOR1_L_IS);
  int raw2 = analogRead(MOTOR2_R_IS) + analogRead(MOTOR2_L_IS);
  motor1Current = (raw1 / 2.0) * (43.0 / 1023.0);
  motor2Current = (raw2 / 2.0) * (43.0 / 1023.0);
}

void checkBattery() {
  int rawADC = analogRead(BATTERY_VOLTAGE);
  batteryVoltage = rawADC * (5.0 / 1023.0) * 5.68;
  
  if (batteryVoltage < BATTERY_CRITICAL) {
    emergencyStop = true;
    tone(BUZZER, 500, 1000);
  } else if (batteryVoltage < BATTERY_LOW_VOLTAGE) {
    static unsigned long lastWarning = 0;
    if (millis() - lastWarning > 10000) {
      tone(BUZZER, 1000, 200);
      lastWarning = millis();
    }
  }
}

void updateGPS() {
  while (Serial1.available()) {
    if (gps.encode(Serial1.read())) {
      if (gps.location.isValid()) {
        latitude = gps.location.lat();
        longitude = gps.location.lng();
      }
      if (gps.speed.isValid()) {
        gpsSpeed = gps.speed.kmph();
      }
      satellites = gps.satellites.value();
    }
  }
}

void applyObstacleAvoidance() {
  if (distanceFront < OBSTACLE_STOP_CM) {
    if (targetSpeed1 > 0 && targetSpeed2 > 0) {
      targetSpeed1 = 0;
      targetSpeed2 = 0;
      tone(BUZZER, 2000, 200);
    }
  }
  else if (distanceFront < OBSTACLE_SLOW_CM) {
    if (targetSpeed1 > 0 && targetSpeed2 > 0) {
      float factor = (float)distanceFront / OBSTACLE_SLOW_CM;
      targetSpeed1 *= factor;
      targetSpeed2 *= factor;
    }
  }
  
  if (distanceLeft < OBSTACLE_SLOW_CM && targetSpeed1 > targetSpeed2) {
    targetSpeed1 = targetSpeed2;
  }
  if (distanceRight < OBSTACLE_SLOW_CM && targetSpeed2 > targetSpeed1) {
    targetSpeed2 = targetSpeed1;
  }
}

void handleButtons() {
  static unsigned long lastDebounce[10] = {0};
  unsigned long now = millis();
  
  if (digitalRead(BTN_SPEED_UP) == LOW && now - lastDebounce[0] > 200) {
    lastDebounce[0] = now;
    if (speedMode < 2) {
      speedMode++;
      tone(BUZZER, 1500, 100);
    }
  }
  
  if (digitalRead(BTN_SPEED_DOWN) == LOW && now - lastDebounce[1] > 200) {
    lastDebounce[1] = now;
    if (speedMode > 0) {
      speedMode--;
      tone(BUZZER, 1000, 100);
    }
  }
  
  if (digitalRead(BTN_MODE) == LOW && now - lastDebounce[2] > 500) {
    lastDebounce[2] = now;
    controlMode = !controlMode;
    tone(BUZZER, controlMode ? 2000 : 1000, 200);
  }
  
  if (digitalRead(BTN_HORN) == LOW) {
    tone(BUZZER, 440, 0);
  } else {
    noTone(BUZZER);
  }
  
  if (digitalRead(BTN_LIGHTS) == LOW && now - lastDebounce[3] > 200) {
    lastDebounce[3] = now;
    lightsOn = !lightsOn;
    Serial2.println(lightsOn ? "LIGHTS:ON" : "LIGHTS:OFF");
  }
  
  if (digitalRead(BTN_AI_ASSIST) == LOW && now - lastDebounce[4] > 500) {
    lastDebounce[4] = now;
    Serial2.println("AI:WAKE");
    tone(BUZZER, 2000, 100);
    delay(100);
    tone(BUZZER, 2500, 100);
  }
  
  if (digitalRead(BTN_CUSTOM1) == LOW && now - lastDebounce[5] > 200) {
    lastDebounce[5] = now;
    fanOn = !fanOn;
    digitalWrite(FAN_CONTROL, fanOn);
  }
  
  if (digitalRead(BTN_CUSTOM2) == LOW && digitalRead(JOYSTICK_BTN) == LOW) {
    if (emergencyStop && now - lastDebounce[6] > 1000) {
      lastDebounce[6] = now;
      emergencyStop = false;
      tone(BUZZER, 1000, 100);
      delay(150);
      tone(BUZZER, 1500, 100);
    }
  }
}

void handleESP32Communication() {
  while (Serial2.available()) {
    char c = Serial2.read();
    if (c == '\n') {
      espBuffer[espBufferIndex] = '\0';
      processESP32Command(espBuffer);
      espBufferIndex = 0;
    } else if (espBufferIndex < 99) {
      espBuffer[espBufferIndex++] = c;
    }
  }
  
  static unsigned long lastStatusUpdate = 0;
  if (millis() - lastStatusUpdate >= 100) {
    lastStatusUpdate = millis();
    sendStatusToESP32();
  }
}

void processESP32Command(char* cmd) {
  if (strncmp(cmd, "MOVE:", 5) == 0) {
    int x, y;
    if (sscanf(cmd + 5, "%d,%d", &x, &y) == 2) {
      // Override implementation
    }
  }
  else if (strcmp(cmd, "STOP") == 0) {
    emergencyStop = true;
    stopMotors();
  }
  else if (strncmp(cmd, "SPEED:", 6) == 0) {
    int newSpeed = atoi(cmd + 6);
    speedMode = constrain(newSpeed, 0, 2);
  }
  else if (strcmp(cmd, "STATUS?") == 0) {
    sendStatusToESP32();
  }
  else if (strncmp(cmd, "GOTO:", 5) == 0) {
    double targetLat, targetLon;
    if (sscanf(cmd + 5, "%lf,%lf", &targetLat, &targetLon) == 2) {
      // Navigation implementation
    }
  }
}

void sendStatusToESP32() {
  Serial2.print("{");
  Serial2.print("\"battery\":");
  Serial2.print(batteryVoltage);
  Serial2.print(",\"speed1\":");
  Serial2.print(currentSpeed1);
  Serial2.print(",\"speed2\":");
  Serial2.print(currentSpeed2);
  Serial2.print(",\"current1\":");
  Serial2.print(motor1Current);
  Serial2.print(",\"current2\":");
  Serial2.print(motor2Current);
  Serial2.print(",\"obstacles\":{");
  Serial2.print("\"front\":");
  Serial2.print(distanceFront);
  Serial2.print(",\"left\":");
  Serial2.print(distanceLeft);
  Serial2.print(",\"right\":");
  Serial2.print(distanceRight);
  Serial2.print("},\"gps\":{");
  Serial2.print("\"lat\":");
  Serial2.print(latitude, 6);
  Serial2.print(",\"lon\":");
  Serial2.print(longitude, 6);
  Serial2.print(",\"sats\":");
  Serial2.print(satellites);
  Serial2.print("},\"mode\":");
  Serial2.print(controlMode);
  Serial2.print(",\"emergency\":");
  Serial2.print(emergencyStop ? "true" : "false");
  Serial2.println("}");
}

void updateStatusLED() {
  static bool ledState = false;
  unsigned long now = millis();
  
  if (emergencyStop) {
    if (now - lastStatusBlink >= 100) {
      ledState = !ledState;
      digitalWrite(LED_STATUS, ledState);
      lastStatusBlink = now;
    }
  }
  else if (!systemReady) {
    if (now - lastStatusBlink >= 1000) {
      ledState = !ledState;
      digitalWrite(LED_STATUS, ledState);
      lastStatusBlink = now;
    }
  }
  else if (batteryVoltage < BATTERY_LOW_VOLTAGE) {
    static uint8_t blinkCount = 0;
    if (now - lastStatusBlink >= 200) {
      if (blinkCount < 4) {
        ledState = !ledState;
        digitalWrite(LED_STATUS, ledState);
        blinkCount++;
      } else if (blinkCount >= 10) {
        blinkCount = 0;
      } else {
        blinkCount++;
      }
      lastStatusBlink = now;
    }
  }
  else {
    digitalWrite(LED_STATUS, HIGH);
  }
}

void manageCooling() {
  bool shouldFanRun = (motor1Current > 10.0 || motor2Current > 10.0) || fanOn;
  
  static bool fanRunning = false;
  static unsigned long fanChangeTime = 0;
  
  if (shouldFanRun && !fanRunning && millis() - fanChangeTime > 5000) {
    fanRunning = true;
    digitalWrite(FAN_CONTROL, HIGH);
    fanChangeTime = millis();
  }
  else if (!shouldFanRun && fanRunning && millis() - fanChangeTime > 30000) {
    fanRunning = false;
    digitalWrite(FAN_CONTROL, LOW);
    fanChangeTime = millis();
  }
}

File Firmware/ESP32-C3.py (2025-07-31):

Add ESP32 board support:
   - File → Preferences → Additional Board URLs
   - Add: https://dl.espressif.com/dl/package_esp32_index.json

Install libraries:
   - ArduinoJson by Benoit Blanchon
   - ESP32 BLE Arduino (comes with ESP32 core)




#include <WiFi.h>
#include <WebServer.h>
#include <ArduinoJson.h>
#include <BLEDevice.h>
#include <BLEServer.h>
#include <BLEUtils.h>
#include <BLE2902.h>

const char* ssid = "MyWiFiNetwork";
const char* password = "MyPassword";

#define BLE_DEVICE_NAME "AI_Wheelchair"
#define SERVICE_UUID "4fafc201-1fb5-459e-8fcc-c5c9c331914b"
#define CHAR_UUID_TX "beb5483e-36e1-4688-b7f5-ea07361b26a8"
#define CHAR_UUID_RX "6e400002-b5a3-f393-e0a9-e50e24dcca9e"

#define ATMEGA_SERIAL Serial1
#define RPI_SERIAL Serial
#define LED_WIFI 2
#define WAKE_WORD_PIN 3

WebServer server(80);
BLEServer* pServer = NULL;
BLECharacteristic* pTxChar;
bool deviceConnected = false;
bool oldDeviceConnected = false;

struct WheelchairStatus {
  float battery;
  int16_t speed1;
  int16_t speed2;
  float current1;
  float current2;
  uint16_t obstacleFront;
  uint16_t obstacleLeft;
  uint16_t obstacleRight;
  double latitude;
  double longitude;
  uint8_t satellites;
  uint8_t mode;
  bool emergency;
} status;

char atmegaBuffer[256];
uint8_t atmegaBufferIndex = 0;
char rpiBuffer[256];
uint8_t rpiBufferIndex = 0;

unsigned long lastWiFiCheck = 0;
unsigned long lastStatusRequest = 0;
unsigned long lastHeartbeat = 0;

class MyServerCallbacks: public BLEServerCallbacks {
  void onConnect(BLEServer* pServer) {
    deviceConnected = true;
  };
  
  void onDisconnect(BLEServer* pServer) {
    deviceConnected = false;
  }
};

class MyCallbacks: public BLECharacteristicCallbacks {
  void onWrite(BLECharacteristic *pCharacteristic) {
    std::string rxValue = pCharacteristic->getValue();
    if (rxValue.length() > 0) {
      for (int i = 0; i < rxValue.length(); i++) {
        ATMEGA_SERIAL.print(rxValue[i]);
      }
      ATMEGA_SERIAL.println();
    }
  }
};

void setup() {
  RPI_SERIAL.begin(115200);
  ATMEGA_SERIAL.begin(115200);
  
  pinMode(LED_WIFI, OUTPUT);
  pinMode(WAKE_WORD_PIN, OUTPUT);
  digitalWrite(WAKE_WORD_PIN, LOW);
  
  setupWiFi();
  setupBLE();
  setupWebServer();
}

void loop() {
  handleATmegaCommunication();
  handleRPiCommunication();
  handleBLE();
  server.handleClient();
  
  if (millis() - lastWiFiCheck >= 10000) {
    checkWiFiConnection();
    lastWiFiCheck = millis();
  }
  
  if (millis() - lastStatusRequest >= 500) {
    requestStatusFromATmega();
    lastStatusRequest = millis();
  }
  
  if (millis() - lastHeartbeat >= 1000) {
    sendHeartbeatToRPi();
    lastHeartbeat = millis();
  }
}

void setupWiFi() {
  WiFi.begin(ssid, password);
  
  int attempts = 0;
  while (WiFi.status() != WL_CONNECTED && attempts < 20) {
    delay(500);
    digitalWrite(LED_WIFI, !digitalRead(LED_WIFI));
    attempts++;
  }
  
  if (WiFi.status() == WL_CONNECTED) {
    digitalWrite(LED_WIFI, HIGH);
  } else {
    digitalWrite(LED_WIFI, LOW);
  }
}

void checkWiFiConnection() {
  if (WiFi.status() != WL_CONNECTED) {
    digitalWrite(LED_WIFI, LOW);
    setupWiFi();
  } else {
    digitalWrite(LED_WIFI, HIGH);
  }
}

void setupBLE() {
  BLEDevice::init(BLE_DEVICE_NAME);
  pServer = BLEDevice::createServer();
  pServer->setCallbacks(new MyServerCallbacks());
  
  BLEService *pService = pServer->createService(SERVICE_UUID);
  
  pTxChar = pService->createCharacteristic(
    CHAR_UUID_TX,
    BLECharacteristic::PROPERTY_NOTIFY
  );
  pTxChar->addDescriptor(new BLE2902());
  
  BLECharacteristic * pRxChar = pService->createCharacteristic(
    CHAR_UUID_RX,
    BLECharacteristic::PROPERTY_WRITE
  );
  pRxChar->setCallbacks(new MyCallbacks());
  
  pService->start();
  pServer->getAdvertising()->start();
}

void handleBLE() {
  if (!deviceConnected && oldDeviceConnected) {
    delay(500);
    pServer->startAdvertising();
    oldDeviceConnected = deviceConnected;
  }
  
  if (deviceConnected && !oldDeviceConnected) {
    oldDeviceConnected = deviceConnected;
  }
  
  if (deviceConnected) {
    static unsigned long lastBLEUpdate = 0;
    if (millis() - lastBLEUpdate >= 1000) {
      sendStatusToBLE();
      lastBLEUpdate = millis();
    }
  }
}

void sendStatusToBLE() {
  char bleStatus[100];
  snprintf(bleStatus, sizeof(bleStatus), 
    "B:%.1f,S:%d,%d,O:%d,%d,%d",
    status.battery,
    status.speed1,
    status.speed2,
    status.obstacleFront,
    status.obstacleLeft,
    status.obstacleRight
  );
  
  pTxChar->setValue(bleStatus);
  pTxChar->notify();
}

void setupWebServer() {
  server.on("/", HTTP_GET, handleRoot);
  server.on("/status", HTTP_GET, handleStatus);
  server.on("/control", HTTP_POST, handleControl);
  server.on("/emergency", HTTP_POST, handleEmergencyStop);
  server.begin();
}
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
